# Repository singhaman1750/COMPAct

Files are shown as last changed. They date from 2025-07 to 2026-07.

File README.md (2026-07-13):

# COMPAct: Actuator design framework

This repository provides an implementation of the paper:

<td style="padding:20px;width:75%;vertical-align:middle">
      <a href="https://arxiv.org/abs/2510.07197" target="_blank">
      <b> COMPAct: Computational Optimization and Automated Modular design of Planetary Actuators </b>
      </a>
      <br>
      <a href="https://singhaman1750.github.io/" target="_blank">Aman Singh</a>, <a href="https://www.linkedin.com/in/deepak-kapa-iitr26/" target="_blank">Deepak Kapa</a>, <a href="https://www.linkedin.com/in/suryank-joshi/" target="_blank">Suryank Joshi</a>, and <a href="https://www.shishirny.com/" target="_blank">Shishir Kolathaya</a>
      <br>
      <em>IEEE International Conference on Robotics and Automation</em>, 2026
      <br>
      <a href="https://youtu.be/99zOKgxsDho?si=5hyMySFOMPunLLCl">Video-Overview</a>
    <br>
</td>

<br>

## COMPAct Flowchart

<p align="center">
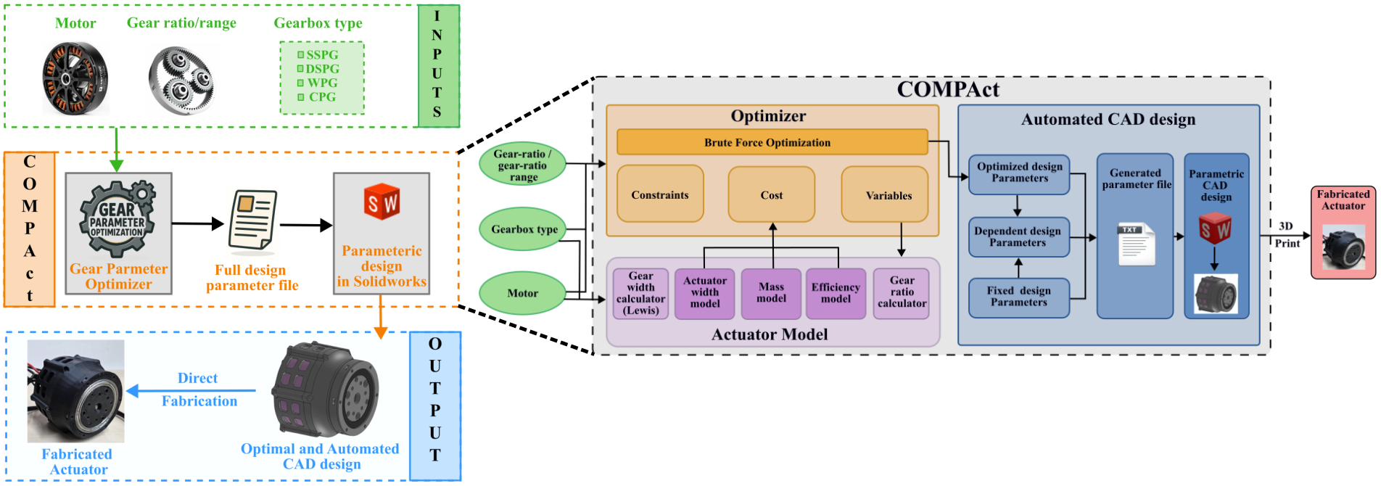
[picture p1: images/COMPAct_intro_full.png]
Flowchart of COMPAct: Actuator Design Framework
  
</p>

---

## Quick Start Guide

#### **Setup & Installations**
* **Step 1:** [Setup & Requirements](#step-1-setup--requirements)
* **Step 2:** [Installation](#step-2-installation)
* **Step 3:** [CAD Automation Setup](#step-3-cad-automation-setup-optional)

#### **Optimization & Automated design generation**
* **Step 4:** [Run Optimization](#step-4-run-optimization)
* **Step 5:** [View Results](#step-5-view-results)
* **Step 6:** [Generate Automated CAD designs](#step-6-generate-automated-cad-designs)
* **Step 7:** [3D-print and Assemble](#step-7-3d-print-and-assemble)

---

### Step 1: Setup & Requirements

#### System Requirements
* **Python 3.x**
* **SolidWorks 2024** (or higher) – *Required for CAD automation features.*

#### Recommended Terminal
* **Windows:** [Git Bash](https://git-scm.com/downloads) is highly recommended.
* **Linux/macOS:** Default terminal.

---

### Step 2: Installation
Clone the repository and install the dependencies:

```bash
# Clone the repository
git clone https://github.com/singhaman1750/COMPAct.git
```

```bash
# Enter the directory
cd COMPAct
```

```bash
# Install required packages
pip install numpy matplotlib pandas requests
```

---

### Step 3: CAD Automation Setup (Optional)

### Option A: *SolidWorks (Local)*

Due to file size limits, CAD files are zipped. You must extract them before running the framework.

**NOTE:** _If you only need the optimized gear parameters (teeth count, module, etc.), you can skip this step. Extraction is only required if you intend to use the **automated 3D modeling**._

1.  Navigate to the `CADs` directory.
2.  Inside each gearbox folder (e.g., `CADs/SSPG/`), unzip the archive (e.g., `sspg_actuator.zip`) into the **same directory**.

Your directory structure should look like this after extraction:
```text
COMPAct-Actuator_design_framework/
└── CADs/
    ├── SSPG/sspg_actuator/sspg_actuator/...
    ├── CPG/cpg_actuator/cpg_actuator/...
    ├── DSPG/dspg_actuator/dspg_actuator/...
    └── WPG/wpg_actuator/wpg_actuator/...
```

### Option B: *Onshape (Cloud-based)*

If you prefer not to use SolidWorks, the CAD models are also available on Onshape. No extraction or local files needed.

#### 1. SSPG (Single-Stage Planetary Gearbox)
[COPY PASTE THE LINK IF HYPERLINK DOESN'T OPEN] 

👉 **[Open SSPG in Onshape](https://cad.onshape.com/documents/c1aac326515ba734f63b9b3f/w/f9cccd7b90ce6d7934076c7c/e/11d494d64974a13f1ae2def2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)**

👉 **[Open CPG in Onshape](https://cad.onshape.com/documents/dabf50453c93c1c427cef77a/w/58e59ba240adf6d2a07794cc/e/2fd7bc338e9316193d1a2f79)**

👉 **[Open WPG in Onshape](https://cad.onshape.com/documents/ad699ddbc25bac5c32e33135/w/758de9a639163030bca8fa73/e/4cb254c85cc1f2d31a39a63a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)**

👉 **[Open DSPG in Onshape](https://cad.onshape.com/documents/b8d43d150fb932ea649dcd0f/w/aaa3fcc8da584cc207374389/e/12e148469fa8eb5b917f5bb1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)**

👉 **[Open ISSPG OutBearing in Onshape](https://cad.onshape.com/documents/bf5f13d9187efab731a95ba7/w/1261f6088846b1d6dd38ea32/e/9442fa2e352d23d6eb88bc6e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)**
```
https://cad.onshape.com/documents/bf5f13d9187efab731a95ba7/w/1261f6088846b1d6dd38ea32/e/9442fa2e352d23d6eb88bc6e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
```

👉 **[Open ISSPG InBearing in Onshape](https://cad.onshape.com/documents/9fa91e98fe82c4e544284d41/w/828f637e6a1fef0940224c5c/e/c80b77fbcf87c09b3b593c8a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)**
```
https://cad.onshape.com/documents/9fa91e98fe82c4e544284d41/w/828f637e6a1fef0940224c5c/e/c80b77fbcf87c09b3b593c8a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
```

👉 **[Open INCPG Dependent in Onshape](https://cad.onshape.com/documents/3e794c46f172f3b02cfa18e7/w/dfc878270d998ca1ea8223c8/e/c324bd70f7c31566e927c1f7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)**
```
https://cad.onshape.com/documents/3e794c46f172f3b02cfa18e7/w/dfc878270d998ca1ea8223c8/e/c324bd70f7c31566e927c1f7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
```

👉 **[Open INCPG Independent in Onshape](https://cad.onshape.com/documents/2519b08c3c51bbdac1923e25/w/095a9ef04c28fad58dcdbe6c/e/7335150ff09908ff2cd1b9b2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)**
```
https://cad.onshape.com/documents/2519b08c3c51bbdac1923e25/w/095a9ef04c28fad58dcdbe6c/e/7335150ff09908ff2cd1b9b2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
```

👉 **[Open INSSPG_Dependent in Onshape](https://cad.onshape.com/documents/97af418b118f30715235cd6a/w/253f8dd6e8e424cb9f7bb1dd/e/bcd4cd4dc6121c4e6915a50e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)**
```
https://cad.onshape.com/documents/97af418b118f30715235cd6a/w/253f8dd6e8e424cb9f7bb1dd/e/bcd4cd4dc6121c4e6915a50e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
```

👉 **[Open INSSPG_Independent in Onshape](https://cad.onshape.com/documents/e0cb8ed6bb2b36cfcadffcf4/w/a5de456488f59701ab182711/e/b8af8d5da69957495c24591f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)**
```
https://cad.onshape.com/documents/e0cb8ed6bb2b36cfcadffcf4/w/a5de456488f59701ab182711/e/b8af8d5da69957495c24591f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 
```

👉 **[Open ICPG in Onshape](https://cad.onshape.com/documents/1cec852caa1080765682d3d0/w/9b7913f319aab1fd6ef5de45/e/f9d06c56e5c97df7f6c68aa9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)** 
```
https://cad.onshape.com/documents/1cec852caa1080765682d3d0/w/9b7913f319aab1fd6ef5de45/e/f9d06c56e5c97df7f6c68aa9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 
```

To get your own editable copy:
1. Open the link above — you will see the model in view-only mode
2. Click the **Onshape logo / menu icon** in the top-left corner
3. Select **"Make a copy"**
4. Give it a name and save it to your own Onshape workspace

> ✅ Your copy is fully independent — any changes you make will **not** affect the original shared document. You can now edit the Variable Studio, modify geometry, and run the automation script against your own copy.

---

### Step 4: Run Optimization
Run the Python script from the root directory to generate optimal gear parameters.

**Syntax:**
```bash
python actOpt.py <motor> <gearbox> <ratio>
```
* **`<motor>`**: U8, U10, U12, MN8014, VT8020, MAD_M6C12 , RO100 , RI100 , RO80
* **`<gearbox>`**: sspg, cpg, dspg, wpg , icpg , insspg_type_1 {Independent} , insspg_type_2 {Dependent} 
* **`<ratio>`**: Must be a value > 2.

**Example:**
To optimize a **RO100** with a **Internal-Compound-Planetary Gearbox** and a **ratio of 6.5**:

```bash
python actOpt_icpg.py RO100 icpg 6.5
```

---
**Example:**
To optimize a **RI100** with a **Inrunner-Dependent-Single-Stage Planetary Gearbox** and a **ratio of 6.5**:

```bash
python actOpt_insspg.py RI100 insspg_type_2 6.5
```

---
**Example:**
To optimize a **RI100** with a **Inrunner-Independent-Single-Stage Planetary Gearbox** and a **ratio of 6.5**:

```bash
python actOpt_insspg.py RI100 insspg_type_1 6.5
```

**Syntax for ISSPG:**  
```bash
python <actuator_type>.py <motor> isspg <ratio>
```
* **`<actuator_type>`**: ISSPG_inside_gen_eq, ISSPG_compact_gen_eq
* **`<motor>`**: RO80, RO100
* **`<ratio>`**: Must be a value > 2.  
Note: ISSPG_inside_gen_eq is for InBearing design and ISSPG_compact_gen_eq is for OutBearing design
  
**Example:**
To optimize **RO100** with an **Internal Single-Stage Planetary Gearbox InBearing** and a **ratio of 6.5**:

```bash
python ISSPG_inside_gen_eq.py RO100 isspg 6.5
```

**Syntax for INCPG:**
```bash
python <actuator_type>.py <motor> incpg <ratio>
```
* **`<actuator_type>`**: InrunnerCPG_independent_gen_eq, InrunnerCPG_dependent_gen_eq
* **`<motor>`**: RI100
* **`<ratio>`**: Must be a value > 2.
  
**Example:**
To optimize **RI100** with an **Inrunner Compound Planetary Gearbox Independent** and a **ratio of 6.5**:

```bash
python InrunnerCPG_independent_gen_eq.py RI100 incpg 6.5
```

---

### Step 5: View Results
The script will output the optimal geometric parameters directly in the terminal:

```text
Running optimization:
  Motor       : U8
  Gearbox     : sspg
  Gear Ratio  : 6.5
Time taken: 0.0196 sec
Optimization Completed.
-------------------------------
Optimal Parameters:
Number of teeth: Sun(Ns): 23 , Planet(Np): 52 , Ring(Nr): 127 , Module(m): 0.6 , NumPlanet(n_p): 3
---
Gear Ratio(GR): 6.52 : 1
-------------------------------
```

Detailed parameter files are automatically generated in the following locations:

* **SSPG:** `CADs/SSPG/sspg_equations.txt`
* **CPG:** `CADs/CPG/cpg_equations.txt`
* **DSPG:** `CADs/DSPG/dspg_equations.txt`
* **WPG:** `CADs/WPG/wpg_equations.txt`
  
#### MASS ANALYSIS
```
https://docs.google.com/spreadsheets/d/1QYUox6946nNlciWFAQ1L-EqQNLNdAT6GV0OtC5uI0eU/edit?usp=sharing
```
---

### Step 6: Generate Automated CAD designs

There are two ways to apply the optimization results to a CAD model — using **SolidWorks** (local) or **Onshape** (cloud-based). Both use the same equations file generated in Step 2.

#### Option A: SolidWorks (Local)

**NOTE:** _If you skipped the CAD extraction in Step 2, you cannot use this option._

1.  Open **SolidWorks**.
2.  Open the assembly file (`.SLDASM`) for your specific gearbox type:
    * **SSPG:** `CADs/SSPG/sspg_actuator/sspg_actuator/sspg_actuator.SLDASM`
    * *(Paths for CPG, DSPG, and WPG follow the same folder pattern)*
3.  Click the **Rebuild** (Traffic Light) icon.
4.  The 3D model will automatically update to reflect the calculated parameters.

---

#### Option B: Onshape (Cloud-based)

This extension lets you push optimization results directly to a parametric Onshape CAD model via the Onshape REST API — no SolidWorks or local CAD files required.

##### i. Make a Copy of the Onshape Document

If you haven't already done so in the extraction step above, open the shared Onshape document and make your own copy:

👉 **[Open SSPG in Onshape](https://cad.onshape.com/documents/c1aac326515ba734f63b9b3f/w/f9cccd7b90ce6d7934076c7c/e/11d494d64974a13f1ae2def2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)**

👉 **[Open CPG in Onshape](https://cad.onshape.com/documents/dabf50453c93c1c427cef77a/w/58e59ba240adf6d2a07794cc/e/2fd7bc338e9316193d1a2f79)**

👉 **[Open WPG in Onshape](https://cad.onshape.com/documents/ad699ddbc25bac5c32e33135/w/758de9a639163030bca8fa73/e/4cb254c85cc1f2d31a39a63a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)**

👉 **[Open DSPG in Onshape](https://cad.onshape.com/documents/b8d43d150fb932ea649dcd0f/w/aaa3fcc8da584cc207374389/e/12e148469fa8eb5b917f5bb1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)**

1. Click the **Onshape logo / menu icon** in the top-left corner
2. Select **"Make a copy"**
3. Give it a name and save it to your own Onshape workspace

> ✅ Your copy is fully independent — any changes the script makes will **not** affect the original shared document.

##### ii. Generate Onshape API Keys

The script authenticates with the Onshape REST API using personal API keys.

1. Go to [dev-portal.onshape.com](https://dev-portal.onshape.com) and sign in
2. Navigate to **API Keys** → **Create New API Key**
3. Copy the **Access Key** and **Secret Key**
4. Create a file named `.env` inside the `Onshape_extension/` folder with the following content:

```env
ONSHAPE_ACCESS_KEY=your_access_key
ONSHAPE_SECRET_KEY=your_secret_key
```

> 🔒 **Never commit your `.env` file.** Make sure `.env` is listed in your `.gitignore`.

##### iii. Get Your Variable Studio URL

The script needs to know which Onshape document and Variable Studio to update. This is done via the URL in your browser.

1. Open your **copied** Onshape document
2. Click on the **Variable Studio** tab at the bottom of the screen (it appears alongside part studios and assemblies)
3. Once you are on the Variable Studio page, copy the **full URL** from your browser's address bar — it will look something like:
   ```
   https://cad.onshape.com/documents/abc123.../w/def456.../e/ghi789...
   ```
4. Open `Onshape_extension/set_values.py` and paste the URL into the `url` field:
   ```python
   doc = Document.from_url(
       url="https://cad.onshape.com/documents/<your-url-here>"
   )
   ```

> 💡 This URL encodes your document ID, workspace ID, and element ID — it is unique to your copy. Using the original shared link will fail as you do not have write access to it.

<!-- ##### iv. Set the Equations File

In `set_values.py`, make sure the equations file name matches the one generated by the optimizer in Step 2. For SSPG this will be:

```python
variables_to_set = parse_variable_file("sspg_equations.txt")
```

Update the filename if you are running a different gearbox type (e.g., `cpg_equations.txt`). -->

##### iv. Run the Script

From the root of the repository:

```bash
cd Onshape_extension
python3 set_values.py
```

The script will print the variable values before and after the update so you can confirm the changes were applied correctly:

```text
=== BEFORE ===
{ ... current variable values ... }

=== SETTING VARIABLE ===
[POST] /api/variables/d/.../w/.../e/.../variables  →  200

=== AFTER ===
{ ... updated variable values ... }
```

> ⚠️ A `200` status does not always mean the update succeeded — Onshape returns 200 even for malformed payloads. Always check the `AFTER` output to confirm your variables were updated as expected.

---

### Step 7: 3D-print and Assemble
* **3D Printing:** Export the updated plastic parts to `.STL` format.
* **Bearings:** Check the updated CAD model to identify which standard bearings are required for your specific configuration.

----

This framework provides the following features:
1. **Optimize planetary gearbox** parameters for a **given motor** across the following gearbox types:
      - Single Stage Planetary Gearbox (SSPG),
      - Compound Planetary Gearbox (CPG),
      - Wolfrom Planetary Gearbox (3K)(WPG), and
      - Double Stage Planetary Gearbox (DSPG).

2. Perform multi-objective optimization to **minimize actuator mass** and **axial width** while **maximizing efficiency**.
3. **Automatically generate parametric actuator CAD** from optimization results, enabling direct **3D printing without manual redesign**.

----

## ✅ Supported Hardware

### Supported Motors
| Motor Code | Description |
| :--- | :--- |
| **U8** | T-motor U8 |
| **U10** | T-motor U10+ |
| **U12** | T-motor U12 |
| **MN8014** | T-motor MN8014 |
| **VT8020** | Vector Techniques 8020 |
| **MAD_M6C12**| MAD Components M6C12 |

### Supported Gearbox Topologies
| Type | Description |
| :--- | :--- |
| **sspg** | Single-Stage Planetary Gearbox |
| **cpg** | Compound Planetary Gearbox |
| **wpg** | Wolfrom Planetary Gearbox (3K) |
| **dspg** | Double-Stage Planetary Gearbox |

---

## 📄 Citation

If you use this framework in your research, please cite:

```bibtex
@misc{singh2025compact,
      title={COMPAct: Computational Optimization and Automated Modular design of Planetary Actuators}, 
      author={Aman Singh and Deepak Kapa and Suryank Joshi and Shishir Kolathaya},
      year={2025},
      eprint={2510.07197},
      archivePrefix={arXiv},
      primaryClass={cs.RO},
      url={https://arxiv.org/abs/2510.07197}, 
}
```

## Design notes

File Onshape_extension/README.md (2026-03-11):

## Quick Start (Run the Project)

### 1. Go to the project root
```bash
cd onshape_toolkit
```
### 2. Activate the virtual environment
```bash
source venv/bin/activate
```
### 4. pip install
```bash
pip install onshape-robotics-toolkit
pip install numpy matplotlib pandas
```

### NOTE 
```bash
AFTER INSTALLING THE "onshape-robotics-toolkit"
Go to connect.py in the library and add the print response statement in the "set_variables" method to see the error
```

### 5. Run the script
```bash
set_values.py
```

# Onshape CAD Automation Toolkit

A Python-based toolkit for programmatic control of Onshape CAD models — enabling parametric variable updates, design automation, and CAD-driven engineering pipelines via the Onshape REST API.

---

## Why This Exists

Most CAD workflows are still manual. Even in parametric design, engineers are left clicking through menus to update dimensions, run sweeps, or test variants.

This toolkit breaks that bottleneck. It lets you treat your CAD model as a programmable object — read variables, push updates, run iterations — all from Python.

Built while working on actuator and mechanism design, where manually updating link lengths across dozens of configurations wasn't sustainable.

---

## Features

- Authenticate with the Onshape API (v9)
- Traverse documents and retrieve elements
- Access and parse Variable Studios
- Read variable names, types, and expressions
- Update variables programmatically with API-compliant payloads
- Handle type-aware updates (`LENGTH`, `ANGLE`, `NUMBER`)
- Structured logging for debugging API responses

---

## Repository Structure

```
onshape-toolkit/
│
├── connect.py              # API client initialization and auth
├── variables.py            # Core variable read/write logic
├── set_values.py           # Script: update specific variables
├── update_variables.py     # Script: batch parametric updates
├── utils/                  # Shared helpers and formatting
├── .env                    # API credentials (not committed)
└── README.md
```

---

## Setup

### 1. Clone

```bash
git clone https://github.com/sakethvegesna/onshape-toolkit.git
cd onshape-toolkit
```

### 2. Install Dependencies

```bash
pip install requests python-dotenv
```

### 3. Configure Credentials

Create a `.env` file in the project root:

```env
ONSHAPE_ACCESS_KEY=your_access_key
ONSHAPE_SECRET_KEY=your_secret_key
ONSHAPE_BASE_URL=https://cad.onshape.com
```

API keys can be generated at [dev-portal.onshape.com](https://dev-portal.onshape.com).

---

## Usage

### Reading Variables

```python
from variables import get_variables

variables = get_variables(document_id, workspace_id, element_id)
print(variables)
```

### Updating Variables

```python
from variables import set_variables

set_variables(
    document_id,
    workspace_id,
    element_id,
    {
        "link_length": "250 mm",
        "joint_width": "40 mm",
        "clearance_angle": "15 deg"
    }
)
```

---

## API Notes

The Onshape Variables API requires strictly formatted payloads. Key implementation details:

- Variables must be sent as **expressions**, not raw numbers (e.g., `"250 mm"` not `250`)
- Each variable requires an explicit **type** field (`LENGTH`, `ANGLE`, `NUMBER`)
- Malformed payloads return 200 OK but silently fail — this toolkit validates before sending
- Developed and tested against Onshape API v9

---

## Use Cases

- Parametric dimension sweeps for mechanism design
- Actuator geometry iteration (link lengths, joint offsets)
- CAD integration into optimization or ML pipelines
- Batch geometry generation for simulation datasets
- Robotics leg/arm configuration studies

---

## Roadmap

- [ ] Assembly-level parameter control
- [ ] Feature creation and suppression
- [ ] STEP/STL export automation
- [ ] Optimization loop integration (e.g., SciPy, Optuna)
- [ ] CLI interface for quick variable updates

---

## Security

Never commit your `.env` file. Add it to `.gitignore`:

```
.env
```

---

## Author

**Saketh Vegesna**  
Mechanical Engineering — Robotics  
Focused on automation, mechanism design, and computational engineering.

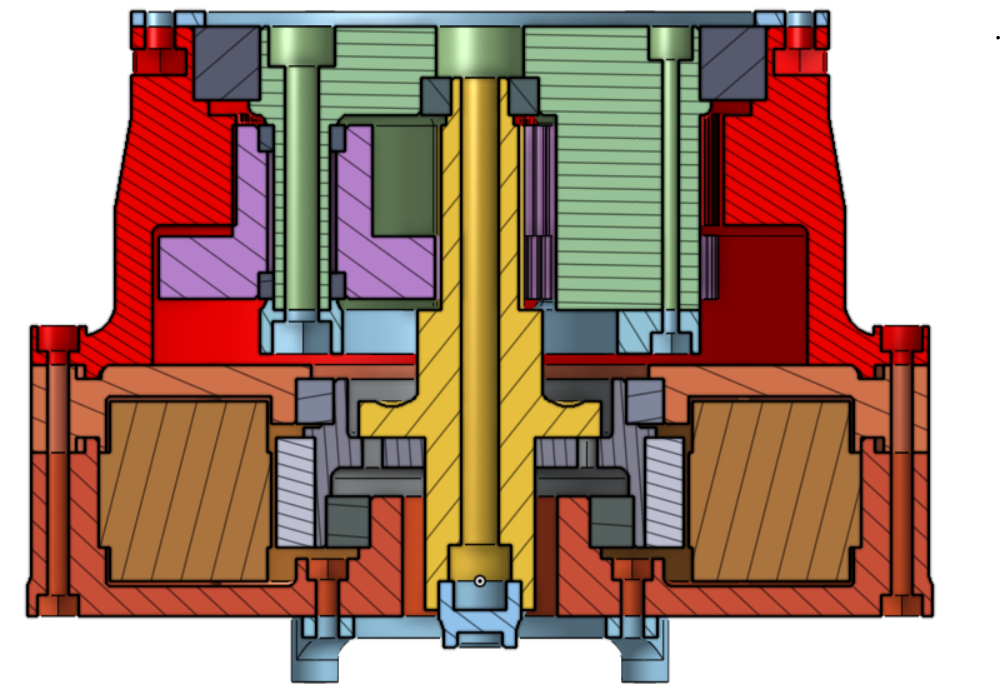
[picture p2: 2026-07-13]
Images/Actuator Cross-Section/INCPG_independent.png

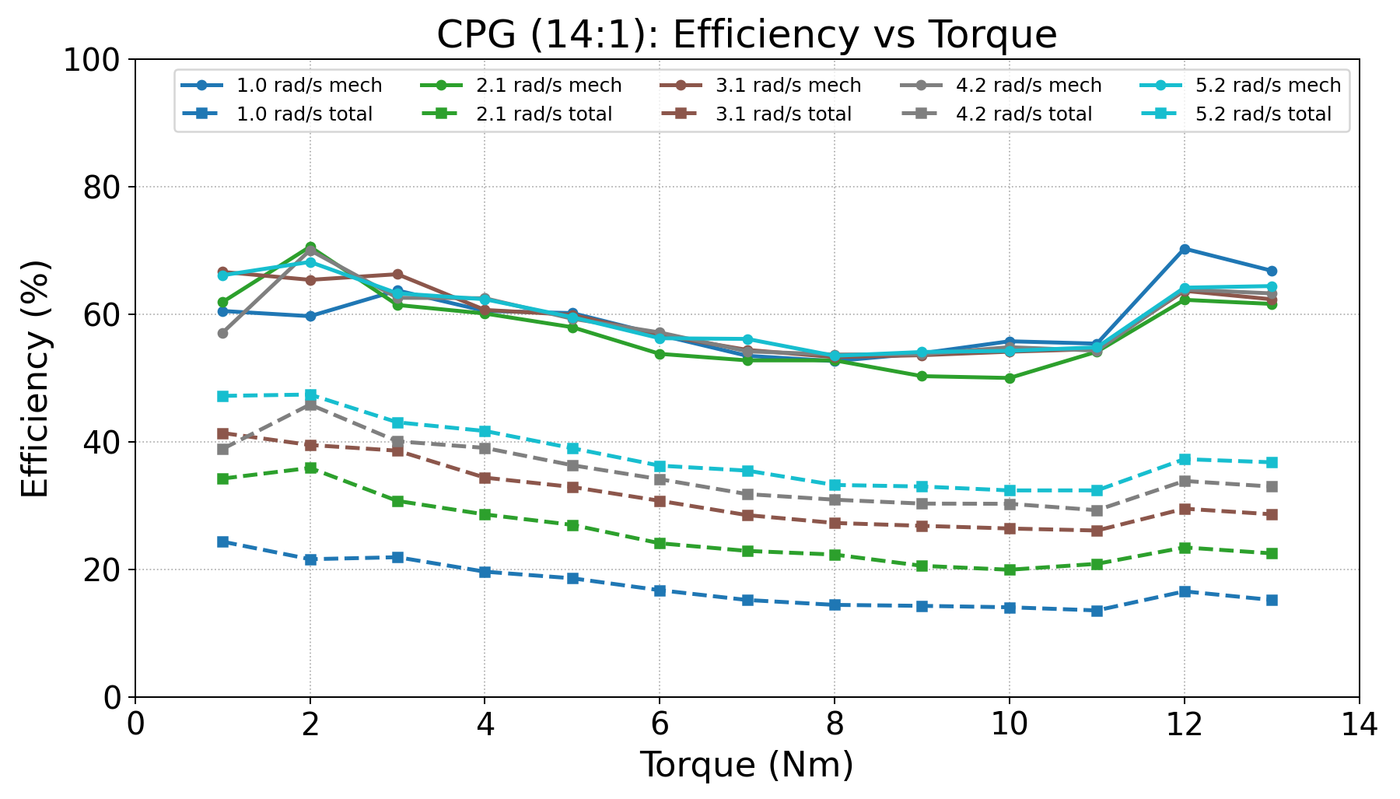
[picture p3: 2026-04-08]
images/CPG_power_eff.png

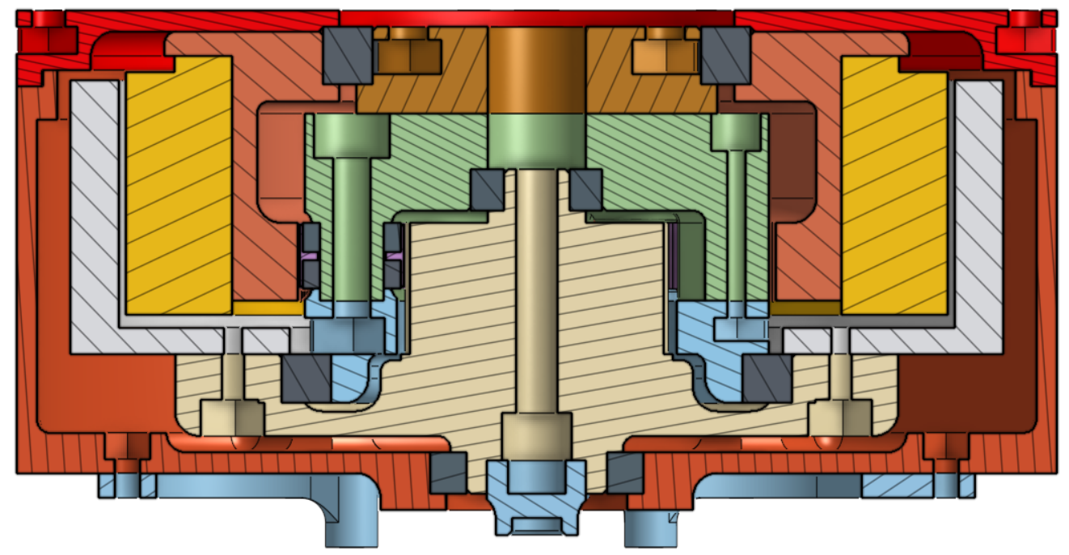
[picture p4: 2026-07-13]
Images/Actuator Cross-Section/ISSPG outside bearing.png

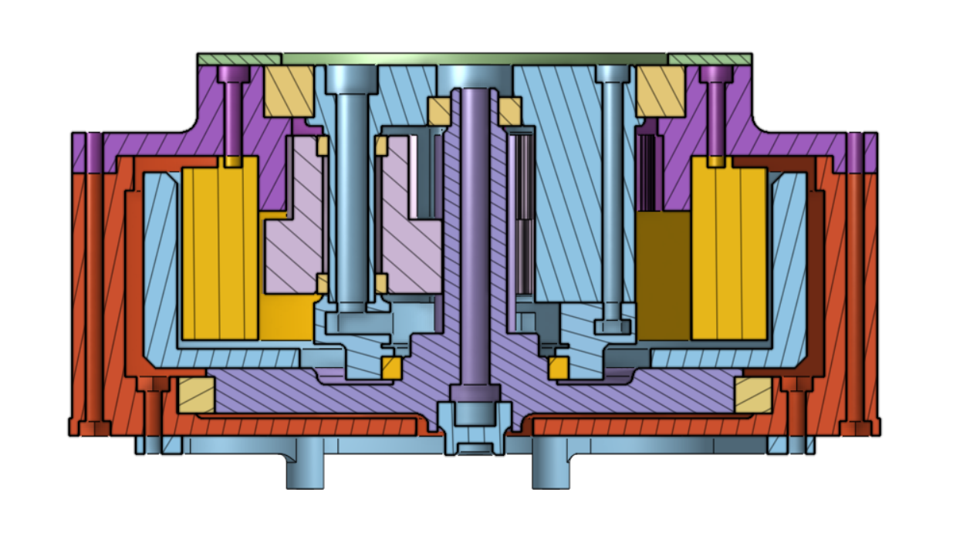
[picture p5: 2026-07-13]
Images/Actuator Cross-Section/ICPG.png

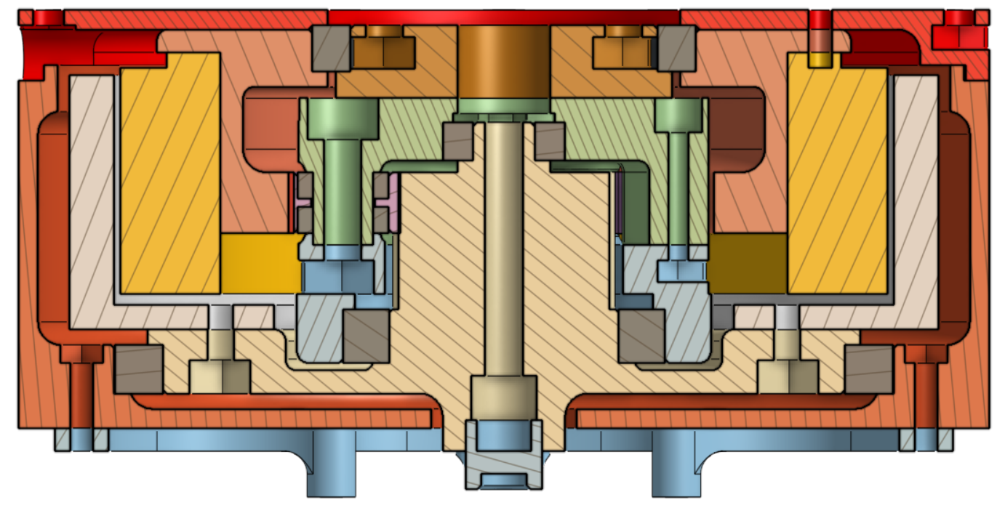
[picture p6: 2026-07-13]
Images/Actuator Cross-Section/ISSPG inside bearing.png

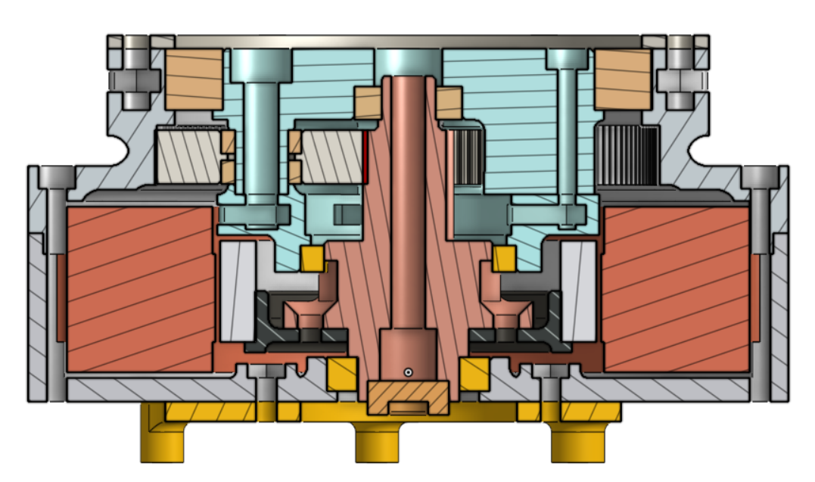
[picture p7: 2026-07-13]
Images/Actuator Cross-Section/INSSPG_Dependent.png

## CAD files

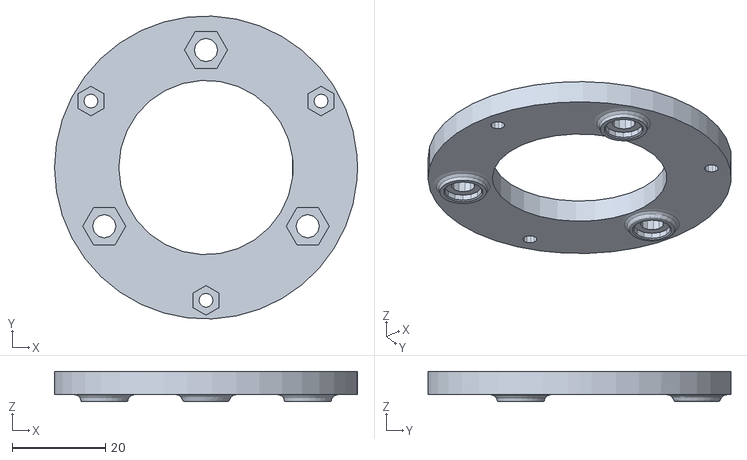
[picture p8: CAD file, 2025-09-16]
CADs/Actuator_STL_files/cpg_14/cpg_sec_carrier.STL
65.0 x 64.9 x 6.50

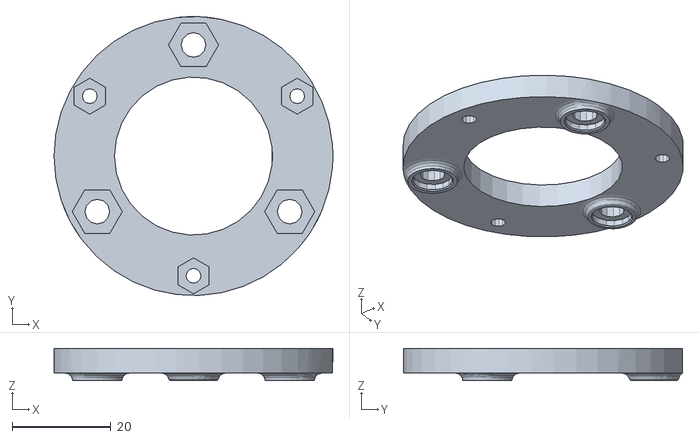
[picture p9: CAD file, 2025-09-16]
CADs/Actuator_STL_files/sspg_7.2/sspg_sec_carrier.STL
56.5 x 56.5 x 6.50

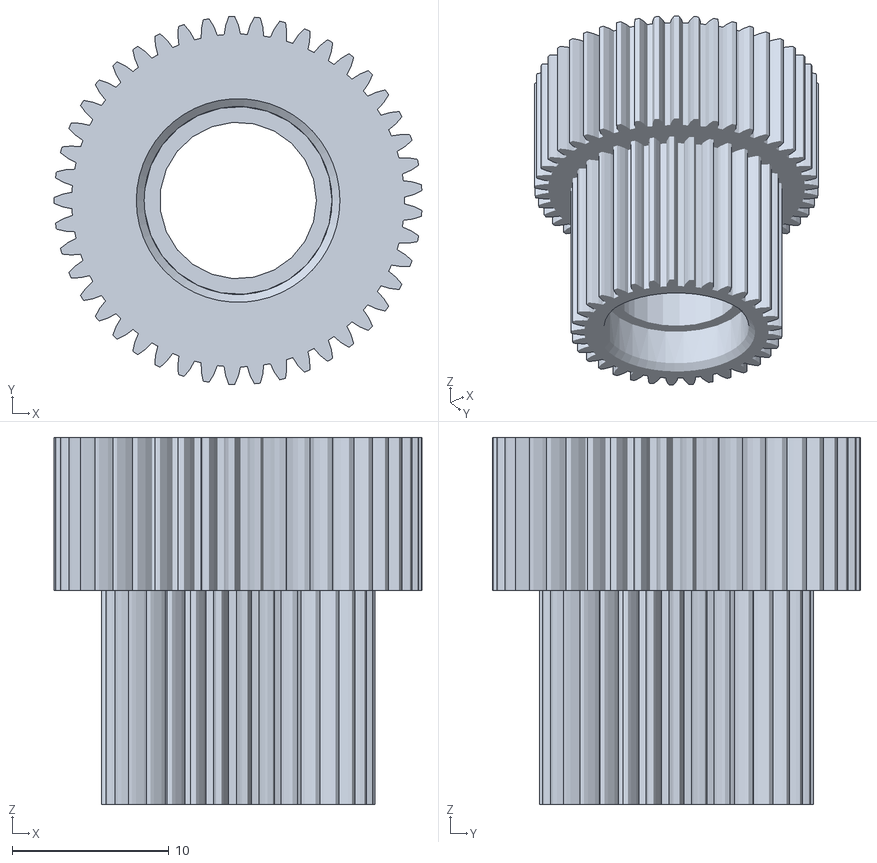
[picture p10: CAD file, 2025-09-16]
CADs/Actuator_STL_files/wpg_16/wpg_planet.STL
23.5 x 23.5 x 23.4

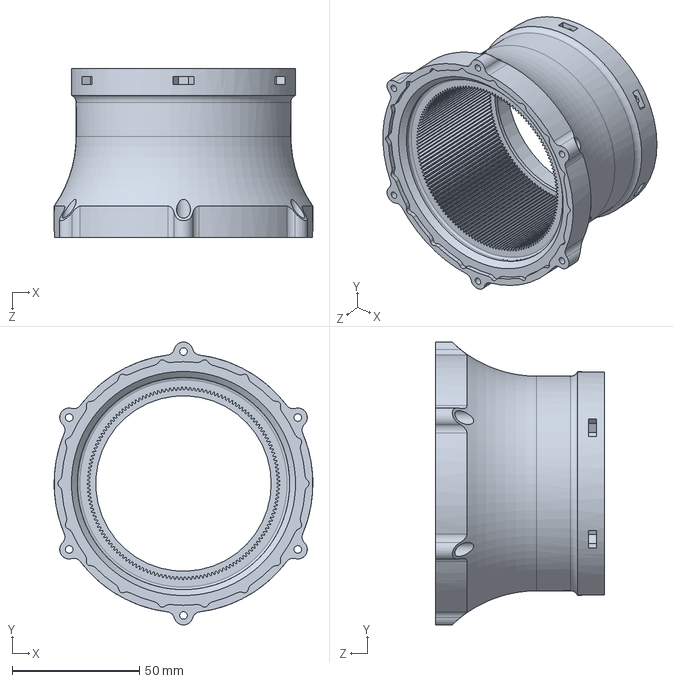
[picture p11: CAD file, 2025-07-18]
SSPG/sspg_gearbox_casing.SLDPRT
101.8 x 111.3 x 66.3 mm

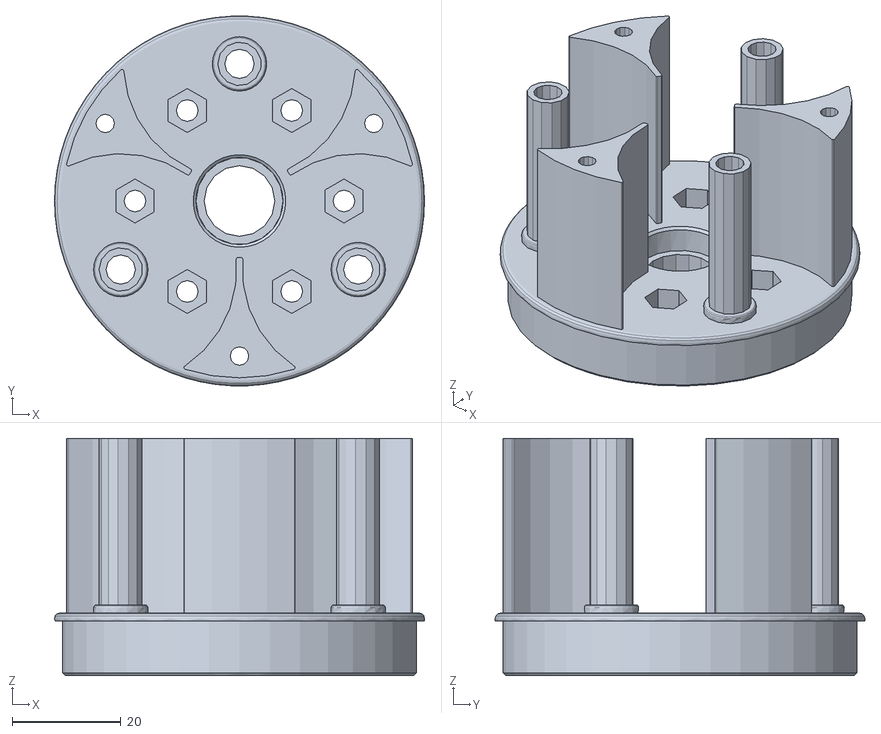
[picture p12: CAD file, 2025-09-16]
CADs/Actuator_STL_files/cpg_14/cpg_carrier.STL
68.0 x 67.9 x 43.6

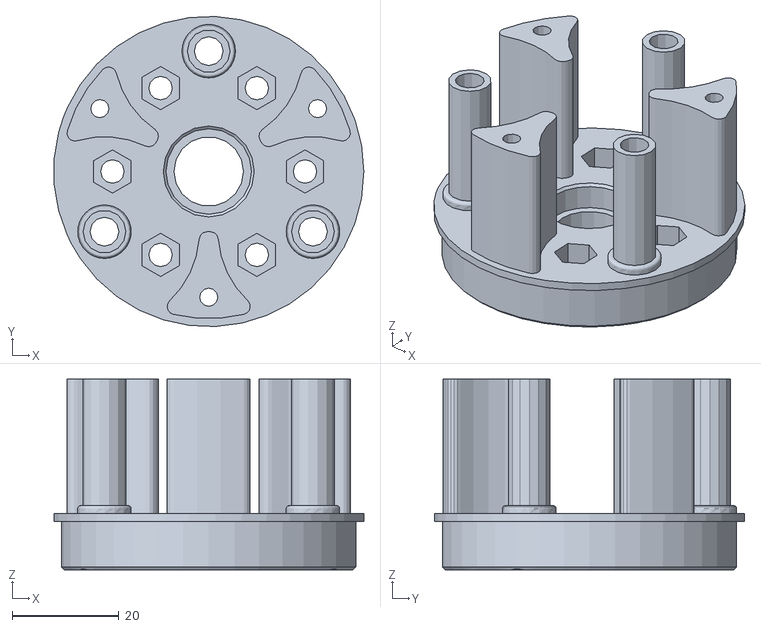
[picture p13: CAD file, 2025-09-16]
CADs/Actuator_STL_files/sspg_7.2/sspg_carrier_updated.STL
57.9 x 57.9 x 35.6

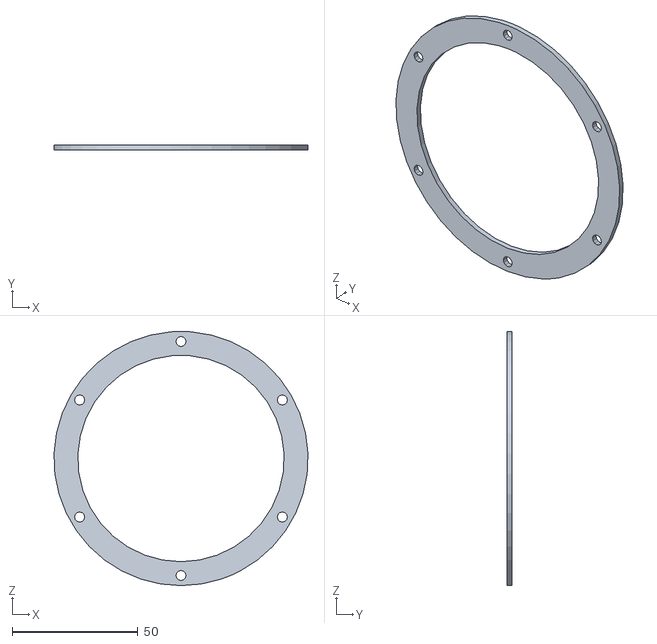
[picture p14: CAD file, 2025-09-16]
CADs/Actuator_STL_files/wpg_16/wpg_bearing_retainer.STL
100.9 x 2.00 x 101.0

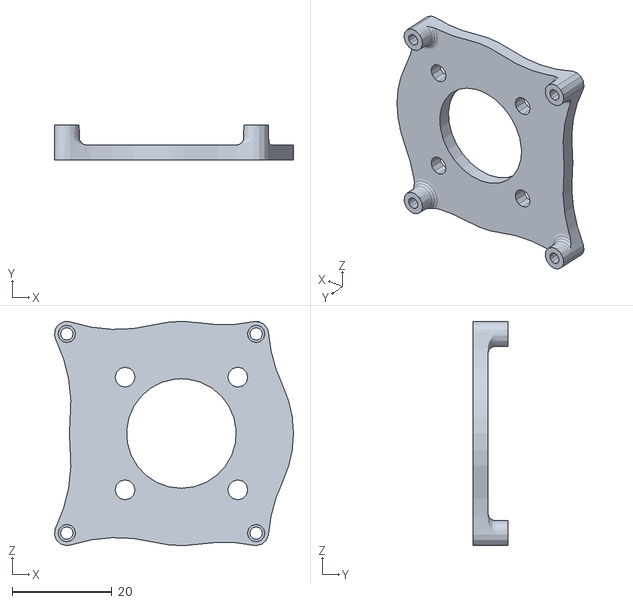
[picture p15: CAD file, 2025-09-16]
CADs/Actuator_STL_files/cpg_14/cpg_driver_mount.STL
48.0 x 7.00 x 45.0

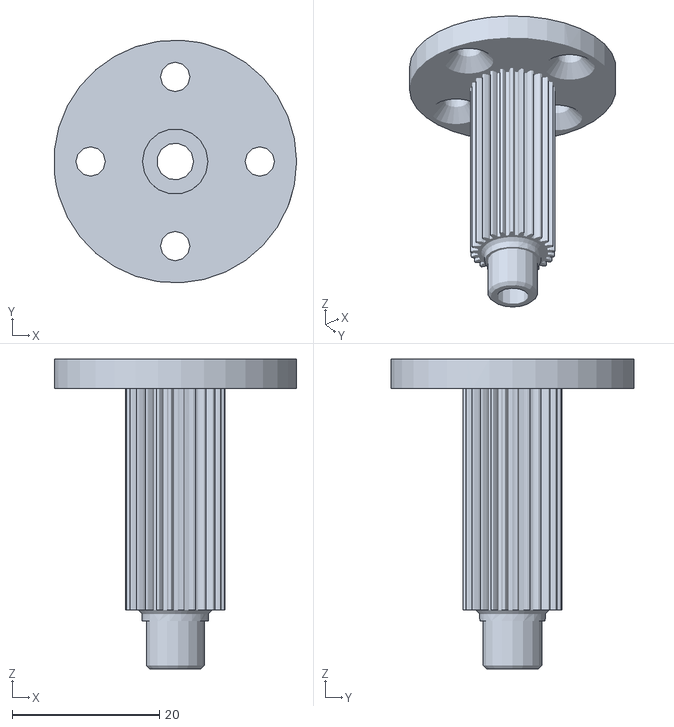
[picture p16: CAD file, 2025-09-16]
CADs/Actuator_STL_files/sspg_7.2/sspg_sun.STL
32.9 x 33.0 x 42.1

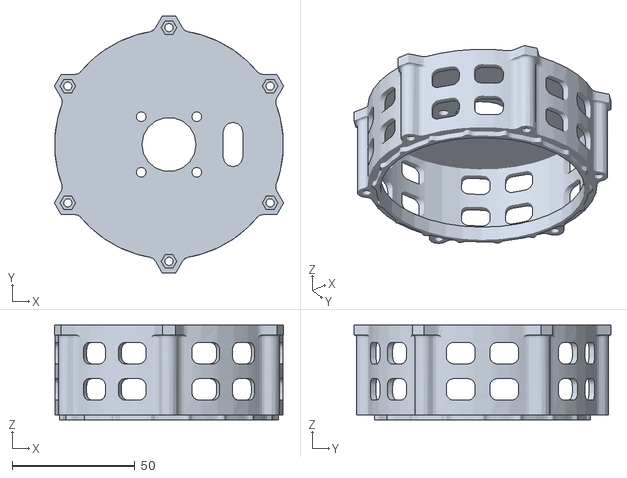
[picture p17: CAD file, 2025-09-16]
CADs/Actuator_STL_files/wpg_16/wpg_motor_casing.STL
93.2 x 104.5 x 38.5

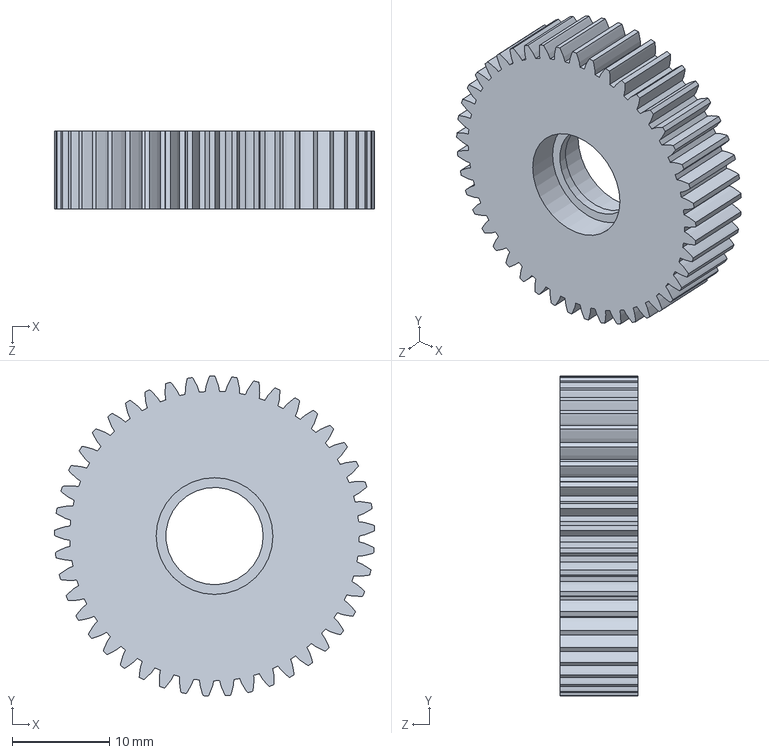
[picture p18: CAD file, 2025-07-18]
SSPG/sspg_planet.SLDPRT
32.9 x 32.9 x 8.00 mm

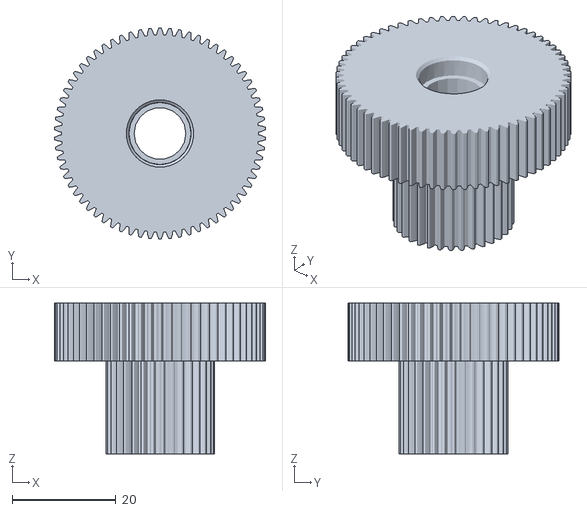
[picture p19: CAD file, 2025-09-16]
CADs/Actuator_STL_files/cpg_14/cpg_planet.STL
40.8 x 40.8 x 29.1

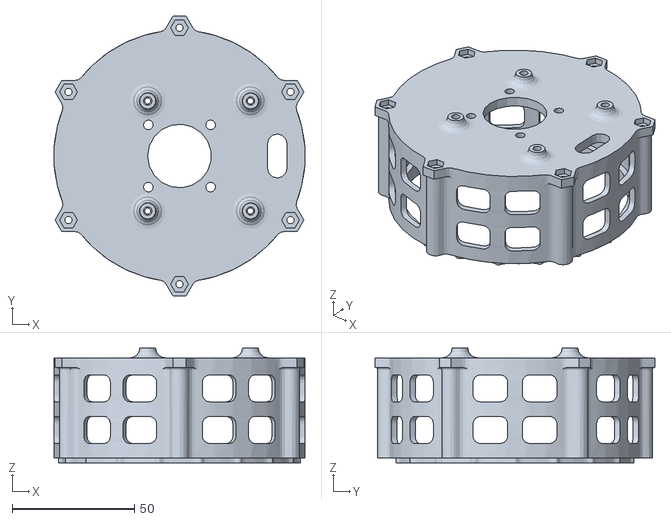
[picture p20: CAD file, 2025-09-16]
CADs/Actuator_STL_files/sspg_7.2/sspg_motor_casing.STL
102.6 x 114.3 x 47.0

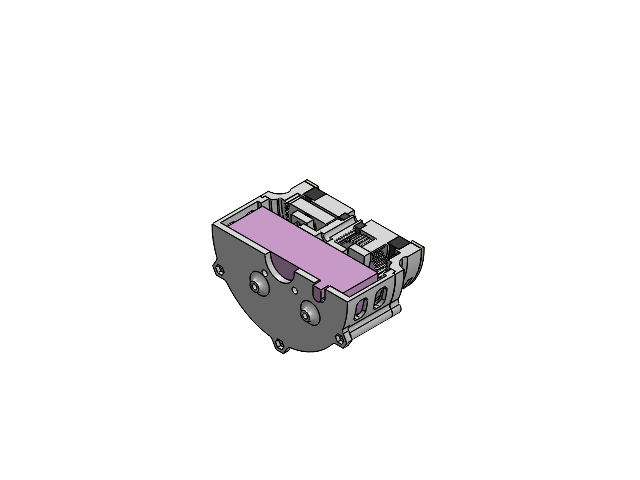
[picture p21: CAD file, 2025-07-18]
SSPG/sspg_actuator.SLDASM
sspg_gearbox_casing
sspg_motor_casing
sspg_sec_carrier
sspg_bearing
sspg_carrier
sspg_planet x 3
sspg_motor
sspg_sun
sspg_planet_bearing x 6
sspg_sun_shaft_bearing
sspg_bearing_retainer

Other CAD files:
CADs/Actuator_STL_files/cpg_14/cpg_bearing_retainer.STL
CADs/Actuator_STL_files/cpg_14/cpg_gearbox_casing.STL
CADs/Actuator_STL_files/cpg_14/cpg_motor_casing.STL
CADs/Actuator_STL_files/cpg_14/cpg_sun.STL
CADs/Actuator_STL_files/sspg_7.2/sspg_bearing_retainer.STL
CADs/Actuator_STL_files/sspg_7.2/sspg_carrier.STL
CADs/Actuator_STL_files/sspg_7.2/sspg_gearbox_casing.STL
CADs/Actuator_STL_files/sspg_7.2/sspg_planet.STL
CADs/Actuator_STL_files/wpg_16/wpg_carrier.STL
CADs/Actuator_STL_files/wpg_16/wpg_driver_mount.STL
CADs/Actuator_STL_files/wpg_16/wpg_gearbox_casing.STL
CADs/Actuator_STL_files/wpg_16/wpg_sec_carrier.STL
CADs/Actuator_STL_files/wpg_16/wpg_small_ring.STL
CADs/Actuator_STL_files/wpg_16/wpg_small_ring_bearing_shaft.STL
CADs/Actuator_STL_files/wpg_16/wpg_sun.STL
CADs/CPG/cpg_actuator/cpg_bearing.SLDPRT
CADs/CPG/cpg_actuator/cpg_bearing_retainer.SLDPRT
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

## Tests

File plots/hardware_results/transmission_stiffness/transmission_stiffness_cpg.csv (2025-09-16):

time_s | encoder_pos_rad | output_torque_Nm
0.010679 | -0.226267082 | 0.025000
0.021350 | -0.225558748 | 0.050000
0.032165 | -0.225842718 | 0.075000
0.042807 | -0.225152455 | 0.100000
0.053697 | -0.224283692 | 0.125000
0.064550 | -0.222317811 | 0.150000
0.075056 | -0.221546561 | 0.175000
0.085633 | -0.219974521 | 0.200000
0.096608 | -0.217884491 | 0.225000
0.107147 | -0.213606263 | 0.250000
0.117720 | -0.204398820 | 0.275000
0.128325 | -0.190740128 | 0.300000
0.138996 | -0.176094750 | 0.325000
0.149552 | -0.166438226 | 0.350000
0.160349 | -0.151883994 | 0.375000
0.170984 | -0.149754500 | 0.400000
0.181688 | -0.151026653 | 0.425000
0.192361 | -0.149551470 | 0.450000
0.203075 | -0.149593087 | 0.475000
0.213770 | -0.149621971 | 0.500000
0.224889 | -0.147608247 | 0.525000
0.235687 | -0.146323875 | 0.550000
0.246268 | -0.144261793 | 0.575000
0.256854 | -0.139245880 | 0.600000
0.267547 | -0.128032577 | 0.625000
0.278244 | -0.110889424 | 0.650000
0.288891 | -0.088638979 | 0.675000
0.299573 | -0.062141249 | 0.700000
0.310316 | -0.028581487 | 0.725000
0.321035 | 0.007464393 | 0.750000
0.331779 | 0.035611312 | 0.775000
0.342472 | 0.041571216 | 0.800000
0.353266 | 0.033364363 | 0.825000
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

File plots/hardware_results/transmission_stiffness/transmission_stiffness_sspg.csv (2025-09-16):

time_s | encoder_pos_rad | output_torque_Nm
0.010764 | -0.262032831 | 0.025000
0.021525 | -0.261688659 | 0.050000
0.032201 | -0.262291240 | 0.075000
0.042922 | -0.261923474 | 0.100000
0.053585 | -0.261790150 | 0.125000
0.064603 | -0.261637726 | 0.150000
0.075477 | -0.261046379 | 0.175000
0.086033 | -0.261244119 | 0.200000
0.096486 | -0.260882719 | 0.225000
0.107111 | -0.260419080 | 0.250000
0.117666 | -0.258979849 | 0.275000
0.128315 | -0.255326159 | 0.300000
0.139002 | -0.230862611 | 0.325000
0.149629 | -0.193940712 | 0.350000
0.160333 | -0.191120674 | 0.375000
0.171046 | -0.190283651 | 0.400000
0.181693 | -0.192024734 | 0.425000
0.192446 | -0.191766698 | 0.450000
0.203217 | -0.190867132 | 0.475000
0.213845 | -0.191086594 | 0.500000
0.225090 | -0.190964504 | 0.525000
0.235822 | -0.190691489 | 0.550000
0.246406 | -0.190659281 | 0.575000
0.256992 | -0.190761147 | 0.600000
0.267596 | -0.190922934 | 0.625000
0.278191 | -0.190753657 | 0.650000
0.288782 | -0.190536068 | 0.675000
0.299460 | -0.190245825 | 0.700000
0.310109 | -0.190111377 | 0.725000
0.320738 | -0.189790799 | 0.750000
0.331439 | -0.189845103 | 0.775000
0.342095 | -0.189897159 | 0.800000
0.352838 | -0.189421161 | 0.825000
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

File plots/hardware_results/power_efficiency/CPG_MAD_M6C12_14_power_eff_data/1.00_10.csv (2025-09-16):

time_s | load_velocity | load_torque | test_velocity | test_torque | loadcell_torque_nm | load_voltage | load_current | test_voltage | test_current
0.01 | -0.00 | -0.13 | -0.11 | 0.00 | -0.02 | 47.82 | 0.00 | 47.89 | -0.00
0.02 | 0.07 | -0.23 | 0.10 | 0.00 | -0.02 | 47.81 | 0.00 | 47.90 | -0.00
0.03 | 0.01 | -0.15 | 0.10 | 0.00 | -0.02 | 47.82 | 0.00 | 47.90 | -0.00
0.03 | 0.10 | -0.27 | 0.16 | 0.00 | -0.02 | 47.82 | 0.00 | 47.89 | -0.00
0.04 | 0.11 | -0.28 | -0.06 | 0.00 | -0.03 | 47.82 | 0.00 | 47.89 | -0.00
0.05 | -0.02 | -0.11 | -0.08 | 0.00 | -0.03 | 47.82 | 0.00 | 47.89 | -0.00
0.07 | 0.13 | -0.31 | -0.04 | 0.00 | -0.03 | 47.82 | 0.00 | 47.89 | 0.00
0.07 | 0.04 | -0.19 | -0.08 | 0.00 | -0.03 | 47.82 | 0.00 | 47.89 | -0.00
0.09 | 0.14 | -0.33 | 0.05 | 0.00 | -0.03 | 47.82 | 0.00 | 47.89 | 0.00
0.10 | 0.04 | -0.20 | 0.10 | 0.00 | -0.03 | 47.83 | 0.00 | 47.90 | 0.00
0.10 | -0.02 | -0.25 | 0.02 | 0.02 | -0.03 | 47.82 | 0.00 | 47.90 | 0.00
0.11 | 0.07 | -0.37 | 0.11 | 0.02 | -0.03 | 47.82 | 0.00 | 47.90 | -0.00
0.12 | -0.00 | -0.28 | -0.08 | 0.02 | -0.03 | 47.82 | 0.00 | 47.90 | 0.00
0.14 | -0.00 | -0.29 | 0.10 | 0.02 | -0.03 | 47.81 | 0.00 | 47.89 | 0.00
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

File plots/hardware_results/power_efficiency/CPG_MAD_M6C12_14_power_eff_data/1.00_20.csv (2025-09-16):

time_s | load_velocity | load_torque | test_velocity | test_torque | loadcell_torque_nm | load_voltage | load_current | test_voltage | test_current
0.01 | 0.01 | -0.27 | -0.12 | 0.00 | -0.00 | 47.82 | 0.00 | 47.89 | -0.00
0.02 | -0.00 | -0.27 | -0.10 | 0.00 | -0.00 | 47.82 | 0.00 | 47.89 | -0.00
0.02 | 0.05 | -0.33 | -0.09 | 0.00 | -0.00 | 47.82 | 0.00 | 47.90 | -0.00
0.04 | -0.16 | -0.07 | 0.05 | 0.00 | -0.00 | 47.82 | 0.00 | 47.89 | 0.00
0.05 | -0.07 | -0.18 | -0.02 | 0.00 | -0.00 | 47.82 | 0.00 | 47.89 | 0.00
0.06 | -0.10 | -0.14 | -0.00 | 0.00 | -0.00 | 47.82 | 0.00 | 47.89 | 0.00
0.07 | 0.01 | -0.30 | 0.06 | 0.00 | -0.00 | 47.82 | 0.00 | 47.89 | -0.00
0.08 | 0.13 | -0.46 | 0.10 | 0.00 | -0.00 | 47.82 | 0.00 | 47.90 | 0.00
0.09 | 0.02 | -0.32 | -0.01 | 0.00 | -0.00 | 47.82 | 0.00 | 47.90 | -0.00
0.10 | -0.01 | -0.28 | -0.04 | 0.00 | -0.00 | 47.82 | 0.00 | 47.89 | -0.00
0.10 | -0.12 | -0.41 | -0.01 | 0.02 | -0.00 | 47.82 | 0.00 | 47.90 | 0.00
0.12 | -0.02 | -0.54 | -0.00 | 0.02 | -0.00 | 47.81 | 0.01 | 47.89 | 0.00
0.13 | -0.06 | -0.50 | 0.07 | 0.02 | -0.00 | 47.82 | 0.01 | 47.89 | -0.00
0.14 | -0.07 | -0.49 | -0.18 | 0.02 | -0.00 | 47.81 | 0.01 | 47.89 | 0.00
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

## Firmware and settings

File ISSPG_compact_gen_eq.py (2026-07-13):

import re
import os
import math
import numpy as np
import sys
import time

# ═══════════════════════════════════════════════════════════════════
#   BEARING LOOKUP CLASS
# ═══════════════════════════════════════════════════════════════════
class bearings_discrete:
    def __init__(self, idRequiredMM, odRequiredMM=0):
        # Bearing dataset entered according to e1102 in [idMM,odMM,widthMM,massKG] format pg no b10-12
        if odRequiredMM != 0 :
            self.data_bearings = [
            [10,19,5,0.005],[12,21,5,0.006],[15,24,5,0.007],[17,26,5,0.007],
            [20,32,7,0.017],[25,37,7,0.021],[30,42,7,0.024],
            [35,47,7,0.027],[44.45,53.975,6.35,0.031],[40,52,7,0.031],[45,58,7,0.038],[50,62,6,0.036],
            [50,65,7,0.050],[55,72,9,0.081],[60,78,10,0.103],[65,85,10,0.128],
            [70,90,10,0.134],[75,95,10,0.149],[80,100,10,0.151],[85,110,13,0.263],
            [90,115,13,0.276],[95,120,13,0.297],[100,125,13,0.31],[105,130,13,0.324],
            [110,140,16,0.497],[120,150,16,0.537],[130,165,18,0.758],[140,170,18,0.832],
            [150,190,20,1.15],[160,200,20,1.23]
            ]
            self.indexBearing = 0
            while self.data_bearings[self.indexBearing][1] < odRequiredMM:
                self.indexBearing += 1            
        else :
            self.data_bearings = [
            [10,19,5,0.005],[12,21,5,0.006],[15,24,5,0.007],[17,26,5,0.007],
            [20,32,7,0.017],[25,37,7,0.021],[28,52,12,0.096],[30,42,7,0.024],
            [32,58,13,0.122],[35,47,7,0.027],[40,52,7,0.031],[45,58,7,0.038],
            [50,65,7,0.050],[55,72,9,0.081],[60,78,10,0.103],[65,85,10,0.128],
            [70,90,10,0.134],[75,95,10,0.149],[80,100,10,0.151],[85,110,13,0.263],
            [90,115,13,0.276],[95,120,13,0.297],[100,125,13,0.31],[105,130,13,0.324],
            [110,140,16,0.497],[120,150,16,0.537],[130,165,18,0.758],[140,170,18,0.832],
            [150,190,20,1.15],[160,200,20,1.23]
            ]
            self.indexBearing = 0
            while self.data_bearings[self.indexBearing][0] < idRequiredMM:
                self.indexBearing += 1

    def getBearingIDMM(self):
        return self.data_bearings[self.indexBearing][0]
    def getBearingODMM(self):
        return self.data_bearings[self.indexBearing][1]
    def getBearingWidthMM(self):
        return self.data_bearings[self.indexBearing][2]
    def getBearingMassKG(self):
        return self.data_bearings[self.indexBearing][3]

class nuts_and_bolts_dimensions:
    def __init__(self, bolt_dia, bolt_type="socket_head"):
        self.bolt_dia  = bolt_dia
        self.bolt_type = bolt_type
        self.bolt_head_dia, self.bolt_head_height = self.get_bolt_head_dimensions(diameter=self.bolt_dia, bolt_type=self.bolt_type)
        self.nut_width_across_flats, self.nut_depth = self.get_nut_dimensions(diameter=self.bolt_dia)

    def get_bolt_head_dimensions(self, diameter, bolt_type="socket_head"):
        diameter = float(diameter)

        socket_head_table = {
            1.6: {"d2": (3.00), "k": (1.60)},
            2.0: {"d2": (3.80), "k": (2.00)},
            2.5: {"d2": (4.50), "k": (2.50)},
            3.0: {"d2": (5.50), "k": (3.00)},
            4.0: {"d2": (7.00), "k": (4.00)},
            5.0: {"d2": (8.50), "k": (5.00)},
            6.0: {"d2": (10.00), "k": (6.00)},
            8.0: {"d2": (13.00), "k": (8.00)},
            10.0: {"d2": (16.00), "k": (10.00)}
        }

        # Only dk is stored for CSK, t is calculated as (dk - d) / 2
        csk_table = {
            3.0: {"dk": 6},
            4.0: {"dk": 8},
            5.0: {"dk": 10},
            6.0: {"dk": 12},
            8.0: {"dk": 16},
            10.0: {"dk": 20},
            12.0: {"dk": 24},
            16.0: {"dk": 30},
            20.0: {"dk": 36}
        }

        if bolt_type == "socket_head":
            spec = socket_head_table.get(diameter)
            if not spec:
                raise ValueError(f"Socket head bolt M{diameter} not found.")
            return [spec["d2"], spec["k"]]  # Return d2, k

        elif bolt_type == "CSK":
            spec = csk_table.get(diameter)
            if not spec:
                raise ValueError(f"CSK bolt M{diameter} not found.")
            dk = spec["dk"]
            t = (dk - diameter) / 2
            return [dk, round(t, 3)]  # Rounded for clarity

        else:
            raise ValueError("bolt_type must be 'socket_head' or 'CSK'")

    def get_nut_dimensions(self, diameter):
        diameter = float(diameter)

        nut_table = {
            2.0: {"width_across_flats": 4, "height": 1.6},
            2.5: {"width_across_flats": 5, "height": 2},
            3.0: {"width_across_flats": 5.5, "height": 2.4},
            4.0: {"width_across_flats": 7, "height": 3.2},
            5.0: {"width_across_flats": 8, "height": 4},
            6.0: {"width_across_flats": 10, "height": 5},
            7.0: {"width_across_flats": None, "height": 5.5},  # ISO not defined
            8.0: {"width_across_flats": 13, "height": 6.5},
            10.0: {"width_across_flats": 16, "height": 8},
            12.0: {"width_across_flats": 18, "height": 10},
            14.0: {"width_across_flats": 21, "height": 13},
            16.0: {"width_across_flats": 24, "height": 13},
            18.0: {"width_across_flats": 27, "height": 15},
            20.0: {"width_across_flats": 30, "height": 16},
            24.0: {"width_across_flats": 36, "height": 18},
            27.0: {"width_across_flats": 40, "height": 20},
            30.0: {"width_across_flats": 43, "height": 22},
        }

        spec = nut_table.get(diameter)
        if not spec:
            raise ValueError(f"No nut data found for bolt diameter M{diameter}")

        width_across_flats = spec["width_across_flats"]
        height = spec["height"]

        return [width_across_flats, height]

class motor:
    
    def __init__(self,
                 motor_OD                     = 92.6,
                 stator_ID                    = 55,
                 motor_rotor_base_thickness   = 2.6,
                 motor_rotor_base_ID          = 51,
                 rotor_height                 = 21.6,
                 rotor_ID                     = 82.6,
                 motor_stator_extrusion_depth = 1.5,
                 motor_stator_extrusion_dia   = 68,
                 stator_height                = 22,
                 stator_OD                    = 81,
                 stator_top_rotor_top_offset  = 4.8,
                 stator_hole_dia              = 3,
                 stator_hole_PCD              = 63,
                 motor_rotor_hole_num         = 6,
                 motor_rotor_hole_dia         = 4.2,
                 motor_rotor_hole_PCD         = 62,
                 motor_height                 = 26.4,
                 maxMotorAngVelRPM            = 5040,  # RPM
                 maxMotorTorque               = 1.3,   # Nm
                 maxMotorPower                = 1.3 * 5040 * 2*np.pi/60,  # W
                 motorMass                    = 0.265, # KG
                 motorName                    = "RO100"):

        self.motorName = motorName

        # Physical geometry
        self.motor_OD                     = motor_OD
        self.stator_ID                    = stator_ID
        self.motor_rotor_base_thickness   = motor_rotor_base_thickness
        self.motor_rotor_base_ID          = motor_rotor_base_ID
        self.rotor_height                 = rotor_height
        self.rotor_ID                     = rotor_ID
        self.motor_stator_extrusion_depth = motor_stator_extrusion_depth
        self.motor_stator_extrusion_dia   = motor_stator_extrusion_dia
        self.stator_height                = stator_height
        self.stator_OD                    = stator_OD
        self.stator_top_rotor_top_offset  = stator_top_rotor_top_offset
        self.stator_hole_dia              = stator_hole_dia
        self.stator_hole_PCD              = stator_hole_PCD
        self.motor_rotor_hole_num         = motor_rotor_hole_num
        self.motor_rotor_hole_dia         = motor_rotor_hole_dia
        self.motor_rotor_hole_PCD         = motor_rotor_hole_PCD   
        self.motor_height                 = motor_height

        #Motor other param
        self.maxMotorAngVelRPM            = maxMotorAngVelRPM
        self.maxMotorAngVelRadPerSec      = maxMotorAngVelRPM * (2 * np.pi / 60)
        self.maxMotorTorque               = maxMotorTorque
        self.maxMotorPower                = maxMotorPower
        self.massKG                       = motorMass     # kg

    # ------------------------------------------------------------------
    # Convenience getters (mirror reference code style)
    # ------------------------------------------------------------------
    
    # Maximum motor angular velocity in rad/s
    def getMaxMotorAngVelRadPerSec(self):
        return self.maxMotorAngVelRadPerSec
    
    # Maximum motor power in W
    def getMaxMotorPower(self):
        return self.maxMotorPower
    
    # Maximum motor torque in Nm
    def getMaxMotorTorque(self):
        return self.maxMotorTorque
    
    # Mass of the motor in kg
    def getMassKG(self):
        return self.massKG

    def getMotorODMM(self):
       return self.motor_OD

    def getMotorHeightMM(self): 
        return self.motor_height

    def getStatorIDMM(self):  
        return self.stator_ID

    def printParameters(self):
        print(f"Motor: {self.motorName}")
        print(f"  motor_OD           = {self.motor_OD} mm")
        print(f"  motor_height       = {self.motor_height} mm")
        print(f"  stator_ID          = {self.stator_ID} mm")
        print(f"  stator_hole_PCD    = {self.stator_hole_PCD} mm")
        print(f"  rotor_height       = {self.rotor_height} mm")

class motor_driver:
    def __init__(self, driver_name, motor_driver_data):
        self.driver_name                          = driver_name
        self.driver_upper_holes_dist_from_center  = motor_driver_data["driver_upper_holes_dist_from_center"]
        self.driver_lower_holes_dist_from_center  = motor_driver_data["driver_lower_holes_dist_from_center"]
        self.driver_side_holes_dist_from_center   = motor_driver_data["driver_side_holes_dist_from_center"]
        self.driver_mount_holes_dia               = motor_driver_data["driver_mount_holes_dia"]
        self.driver_mount_inserts_OD              = motor_driver_data["driver_mount_inserts_OD"]
        self.driver_mount_thickness               = motor_driver_data["driver_mount_thickness"]
        self.driver_mount_height                  = motor_driver_data["driver_mount_height"]

        # self.print_vars()
    
    def print_vars(self):
        print("driver_name:", self.driver_name)
        print("driver_upper_holes_dist_from_center: ", self.driver_upper_holes_dist_from_center)
        print("driver_lower_holes_dist_from_center: ", self.driver_lower_holes_dist_from_center)
        print("driver_side_holes_dist_from_center: ", self.driver_side_holes_dist_from_center)
        print("driver_mount_holes_dia: ", self.driver_mount_holes_dia)
        print("driver_mount_inserts_OD: ", self.driver_mount_inserts_OD)
        print("driver_mount_thickness: ", self.driver_mount_thickness)
        print("driver_mount_height: ", self.driver_mount_height)
        print("---")

class internalsingleStagePlanetaryGearbox:
    def __init__(self, 
                 design_params,
                 gear_standard_parameters,
                 Ns                        = 20,
                 Np                        = 40,
                 Nr                        = 100,
                 module                    = 0.5,
                 numPlanet                 = 3,
                 fwSunMM                   = 5.0,
                 fwPlanetMM                = 5.0,
                 fwRingMM                  = 5.0,
                 maxGearAllowableStressMPa = 400,
                 densityGears              = 1246,
                 densityStructure          = 1246,
                 ):
        
        self.Ns        = Ns
        self.Np        = Np
        self.Nr        = Nr
        self.numPlanet = numPlanet
        self.module    = module

        self.maxGearAllowableStressMPa = maxGearAllowableStressMPa # MPa
        self.maxGearAllowableStressPa  = maxGearAllowableStressMPa * 10**6 # Pa
        self.densityGears              = densityGears
        self.densityStructure          = densityStructure
        self.bhnSun                    = 270 # Brinell Hardness Number for sun gear
        self.bhnPlanet                 = 270 # Brinell Hardness Number for planet gear
        self.bhnRing                   = 270 # Brinell Hardness Number for ring gear
        self.enduranceStressSunMPa     = 2.75*self.bhnSun - 69    # MPa
        self.enduranceStressPlanetMPa  = 2.75*self.bhnPlanet - 69 # MPa
        self.enduranceStressRingMPa    = 2.75*self.bhnRing - 69   # MPa
        self.youngsModulusSun          = 2.05 * 10**5 # MPa 
        self.youngsModulusPlanet       = 2.05 * 10**5 # MPa 
        self.youngsModulusRing         = 2.05 * 10**5 # MPa 
        self.equivYoungsModulusSP      = (2.0 * self.youngsModulusSun * self.youngsModulusPlanet) / (self.youngsModulusSun + self.youngsModulusPlanet)
        self.equivYoungsModulusPR      = (2.0 * self.youngsModulusPlanet * self.youngsModulusRing) / (self.youngsModulusPlanet + self.youngsModulusRing)

        # Face width of sun gear, planet gear, and ring gear in mm
        self.fwSunMM    = fwSunMM
        self.fwRingMM   = fwRingMM
        self.fwPlanetMM = fwPlanetMM

        # Face width of sun gear, planet gear, and ring gear in m
        self.fwSunM     = fwSunMM / 1000.0
        self.fwRingM    = fwRingMM / 1000.0
        self.fwPlanetM  = fwPlanetMM / 1000.0

        # Coefficient of friction and Pressure Angles
        self.mu            = gear_standard_parameters["coefficientOfFriction"] # 0.3 # Coefficient of friction
        self.pressureAngle = gear_standard_parameters["pressureAngleDEG"]      # 20  # deg

        self.planetMinDistanceMM = design_params["planetMinDistanceMM"]        # mm
        
        self.sCarrierExtrusionDiaMM       =  design_params["sCarrierExtrusionDiaMM"]       # 8.0 # mm
        self.sCarrierExtrusionClearanceMM =  design_params["sCarrierExtrusionClearanceMM"] # 1.0 # mm
    
    #------------------------------------
    # Constraints
    #------------------------------------
    def geometricConstraint(self):
        return (self.Ns + 2*self.Np == self.Nr) 
    
    def meshingConstraint(self):
        return ((self.Ns + self.Nr) % self.numPlanet == 0)

    def noPlanetInterferenceConstraint_old(self):
        return 2*(self.Ns + self.Np)*self.module*np.sin(np.pi/self.numPlanet) >= 2*self.module*self.Np + self.planetMinDistanceMM

    # New incorporates the extrusion diameter
    def noPlanetInterferenceConstraint(self):
        Rs                        = (self.module) * self.Ns / 2
        Rp                        = (self.module) * self.Np / 2 
        numPlanet                 = self.numPlanet
        sCarrierExtrusionRadiusMM = self.sCarrierExtrusionDiaMM * 0.5
        return 2 * (Rs + Rp) * np.sin(np.pi/(2*numPlanet)) - Rp - sCarrierExtrusionRadiusMM >= self.sCarrierExtrusionClearanceMM * 2

    #------------------------------------
    # Gear ratio
    #------------------------------------
    def gearRatio(self):
        return (self.Nr + self.Ns) / self.Ns

    #-------------------------------------------------------------------------
    # Uitility Functions
    #-------------------------------------------------------------------------
    def inverse_involute(self,inv_alpha):
        # This is an approximation of the inverse involute function
        alpha  = ((3*inv_alpha)**(1/3) - 
                  (2*inv_alpha)/5 + 
                  (9/175)*(3)**(2/3)*inv_alpha**(5/3) - 
                  (2/175)*(3)**(1/3)*(inv_alpha)**(7/3) - 
                  (144/67375)*(inv_alpha)**(3) + 
                  (3258/3128125)*(3)**(2/3)*(inv_alpha)**(11/3) - 
                  (49711/153278125)*(3)**(1/3)*(inv_alpha)**(13/3))
        return alpha

    def involute(self,alpha):
        return (np.tan(alpha) - alpha)

    # Define the differentiable quadratic approximation of the min function
    def quadratic_min(self, a, b, k=0.01):
        return (a + b - np.sqrt((a - b)**2 + k**2)) / 2
    
    #-------------------------------------------------------------------------
    # Gear Tooth profile parameters
    #-------------------------------------------------------------------------
    def getPressureAngleRad(self):
        return self.pressureAngle * np.pi / 180  # Pressure angle in radians

    def getWorkingPressureAngle(self):
        module = self.module  # Module of the gear
        Ns     = self.Ns
        Np     = self.Np
        Nr     = self.Nr
        xs     = 0.0 # self.PSCs
        xp     = 0.0 # self.PSCp
        xr     = 0.0 # self.PSCr
        
        #---------------------------------
        # Pressure Angle
        #---------------------------------
        alpha = self.getPressureAngleRad()

        #---------------------------------
        # Working pressure angle
        #---------------------------------
        # Sun-Planet
        inv_alpha_w_sunPlanet = 2*np.tan(alpha)*((xs + xp)/(Ns + Np)) + self.involute(alpha)
        alpha_w_sunPlanet = self.inverse_involute(inv_alpha_w_sunPlanet)

        # Planet-Ring
        inv_alpha_w_planetRing = 2*np.tan(alpha)*((xr-xp)/(Nr - Np)) + self.involute(alpha)
        alpha_w_planetRing = self.inverse_involute(inv_alpha_w_planetRing)

        return alpha_w_sunPlanet, alpha_w_planetRing

    def getCenterDistModificationCoeff(self):
        module = self.module  # Module of the gear
        Ns     = self.Ns
        Np     = self.Np
        Nr     = self.Nr
        xs     = 0.0 # self.PSCs
        xp     = 0.0 # self.PSCp
        xr     = 0.0 # self.PSCr
        
        #------------------------------
        # Pressure Angle
        #------------------------------
        alpha = self.getPressureAngleRad()  # Pressure angle in radians

        #------------------------------
        # Working pressure angle
        #------------------------------
        alpha_w_sunPlanet, alpha_w_planetRing = self.getWorkingPressureAngle()

        #------------------------------
        # Centre distance modification coefficient
        #------------------------------
        y_sunPlanet  = ((Ns + Np) / 2) * ((np.cos(alpha) / np.cos(alpha_w_sunPlanet)) - 1)
        y_planetRing = ((Nr - Np) / 2) * ((np.cos(alpha) / np.cos(alpha_w_planetRing)) - 1)

        return y_sunPlanet, y_planetRing

    def getCenterDistance(self):
        module = self.module  # Module of the gear
        Ns     = self.Ns
        Np     = self.Np
        Nr     = self.Nr
        xs     = 0.0 # self.PSCs
        xp     = 0.0 # self.PSCp
        xr     = 0.0 # self.PSCr

        #-------------------------------
        # Centre distance modification coefficient
        #-------------------------------
        y_sunPlanet, y_planetRing = self.getCenterDistModificationCoeff()

        #-------------------------------
        # Centre distance
        #-------------------------------
        centerDist_sunPlanet = ((Ns + Np)/2  + y_sunPlanet)* module
        centerDist_planetRing = ((Nr - Np)/2  + y_planetRing)* module

        return centerDist_sunPlanet, centerDist_planetRing

    def getBaseDia(self):
        module = self.module  # Module of the gear
        Ns     = self.Ns
        Np     = self.Np
        Nr     = self.Nr
        xs     = 0.0 # self.PSCs
        xp     = 0.0 # self.PSCp
        xr     = 0.0 # self.PSCr

        # Pressure Angle
        alpha = self.getPressureAngleRad() # Rad

        # Reference Diameter
        D_sun    = module * Ns # Sun's reference diameter
        D_planet = module * Np # Planet's reference diameter
        D_ring   = module * Nr # Ring's reference diameter

        # Base Diameter
        D_b_sun    = D_sun * np.cos(alpha)
        D_b_planet = D_planet * np.cos(alpha)
        D_b_ring   = D_ring * np.cos(alpha)

        return D_b_sun, D_b_planet, D_b_ring

    def getTipCircleDia(self):
        module = self.module  # Module of the gear
        Ns     = self.Ns
        Np     = self.Np
        Nr     = self.Nr
        xs     = 0.0 # self.PSCs
        xp     = 0.0 # self.PSCp
        xr     = 0.0 # self.PSCr

        #----------------------------
        # Pressure Angle
        #----------------------------
        alpha = self.getPressureAngleRad() # Rad

        #----------------------------
        # Reference Diameter
        #----------------------------
        D_sun    = module * Ns # Sun's reference diameter
        D_planet = module * Np # Planet's reference diameter
        D_ring   = module * Nr # Ring's reference diameter

        #----------------------------
        # Center Distance Modification Coefficient
        #----------------------------
        y_sunPlanet, y_planetRing = self.getCenterDistModificationCoeff()

        #----------------------------
        # Tip circle diameter
        #----------------------------
        # Sun
        D_a_sun = D_sun + 2 * module * (1 + y_sunPlanet - xp)

        # Planet
        D_a_planet = D_planet + 2 * module * (1 + self.quadratic_min((y_sunPlanet - xs), xp))  
        # D_a_planet = D_planet + 2 * module * (1 + self.quadratic_min((y_planetRing - xs),xp)) 
        # D_a_planet = D_planet + 2 * module * (1 + xp) 
        
        # Ring
        D_a_ring = D_ring - 2 * module * (1 - xr)
        
        return D_a_sun, D_a_planet, D_a_ring

    def getTipPressureAngle(self):
        module = self.module  # Module of the gear
        Ns     = self.Ns
        Np     = self.Np
        Nr     = self.Nr
        xs     = 0.0 # self.PSCs
        xp     = 0.0 # self.PSCp
        xr     = 0.0 # self.PSCr
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

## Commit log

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2025-07-16 Added correct equation files
    [Opt_singleStagePlanetaryGBOptimization.py]
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2025-07-16 Bug Fix in equation file
    [Opt_singleStagePlanetaryGBOptimization.py]
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2025-07-28 Bug fix in DSPG
    [Opt_doubleStagePlanetaryGBOptimization.py]
2025-08-03 changes in cpg and mass bug fix
    [Opt_compoundPlanetaryGBOptimization.py]
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2025-08-07 in the previous commit the material denisty is correctly entered. -- #30
    [Opt_compoundPlanetaryGBOptimization.py, Opt_doubleStagePlanetaryGBOptimization.py, Opt_singleStagePlanetaryGBOptimization.py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]
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2025-08-27 added SSPG final code, corrected density, fixed max gb dia, separate gen_eq_file, bearing mass added to results, provision for optimizing for a given gear-ratio, provision for printing the optimizati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
    [Opt_singleStagePlanetaryGBOptimization.py]
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2025-08-31 completed the dspg code, added wpg outer bearing mass and actuator width, fixed the bearing mass bug in WPG, yet the cpg, wpg, and dspg actuator widths are set to 0. will correct them in next code
    [Opt_doubleStagePlanetaryGBOptimization.py]
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2025-08-31 corrected a small bug in dspg
    [Opt_doubleStagePlanetaryGBOptimization.py]
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2025-09-16 added stiffness data and plot files
    [stiffness_20250908_161640.csv, stiffness_20250908_172116.csv]
2025-09-16 added transmission stiffness properly
    [transmission_stiffness_cpg.csv, transmission_stiffness_sspg.csv]
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2026-06-22 ISSPG: Update mass function for two CAD designs
    Problem
    =======
    1. Mass function update required for the new ISSPG designs.
    Solution
    ========
    1. Changed the equation of fw_s_used.
    2. Changed the mass function according to the recent changes in the CAD.
    Note
    ====
    1. Added result file for RO60.
    2. Added ISSPG_inside_gen_eq.py and ISSPG_compact_gen_eq.py for the two different cads.
    [ISSPG_BRUTEFORCE_MIT_RO100.csv, ISSPG_BRUTEFORCE_MIT_RO60.csv, ISSPG_BRUTEFORCE_MIT_RO80.csv]
2026-06-22 Updated Parse file to work with ISSPG Problem ======= Few variables which were newly added to the onshape CAD have to be updated in parse file
    Update parse_variables_txt.py to include number variables
    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
    [ISSPG_inside_gen_eq.py]
2026-06-22 Updated json files
    The range of fesable gearboxes was little due to carrier extrusion diameter being 8.
    Density of PLA mismatched that of PLA given in Onshape
    Changed the value of carrier extrusion diameter to 7 and clearance to 0.5.
    Chnaged density value so that mass function gives correct value.
    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
2026-07-01 Added Optimization Code for Inrunner Compound Planetary Gearbox type1
    Writing optimization code for Inrunner Compound Planetary Gearbox type1 to find the optimal design parameters for a given motor and gear ratio.
    Added a new python file InrunnerCPG_type1_gen_eq.py which contains the optimization code.
    Wrote the mass function.
    Added incpg_params.json file to store the parameters.
    Added Results file.
    Updated the density of aluminum in the config.json file to 2700 from 2710.
    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
    [INCPG_BRUTEFORCE_MIT_RI100.csv]
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2026-07-01 Updated Parse file to work with INCPG
    Few variables which were newly added to the onshape CAD have to be updated in parse file
    Updated parse_variables_txt.py to include number variables
    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
2026-07-01 Added new variables, Updated mass function
    The CAD ran into some errors due to ring_radial_width being used for gearbox casing thickness.
    Added a new variable for gearbox thickness and updated the mass fucntion accordingly
    Changed name of gearbox from type 1 to independent
    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
    [InrunnerCPG_independent_gen_eq.py]
2026-07-01 Added Constraints for Sun PCD, Planet PCD in Inrunner CPG
    1. Sun gear became smaller than sun shaft bearing ID.
    2. Planet gear became smaller than planet bearing OD if minimum number of teeth on planet gear is 28 but the constraint should be on PCD.
    3. Primary Planet Gear had smaller number of teeth that Secondary Planet Gear in some cases.
    1. Added constraint for Sun PCD to be greater than Sun Shaft Bearing ID.
    2. Added constraint for Planet PCD to be greater than Planet Bearing OD.
    3. Added constraint for Primary Planet Gear to have greater number of teeth than Secondary Planet Gear.
    1. Changed the max gearbox dia mult factor from 0.8 to 0.85 t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
    [InrunnerCPG_independent_gen_eq.py]
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2026-07-03 Updated Mass function and setvariables for changes in CAD.
    Mass function and setvariables should be updated to accomodate for the changes in CAD.
    Updated the mass fucntion and setvariables.
    Chnaged the no carrier constraint from 1*module to 1.25*module
    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
    [InrunnerCPG_independent_gen_eq.py]
2026-07-03 Added Optimisation code for Inrunner CPG (dependent)
    Optimizing the INCPG (dependent) actuator
    Added all the files required to run optimization.
    Dependent means that the motor can not run without the gearbox attached.
    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
    [InrunnerCPG_dependent_gen_eq.py, Opt_dependentInrunnerCompoundPlanetaryGBOptimization.py]
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2026-07-08 Removed a file, Minor changes in files.
    ISSPG_outside_gen_eq.py file was not needed anymore.
    Deleted the file.
    Updated result file output fields.
    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
    [ISSPG_compact_gen_eq.py, ISSPG_inside_gen_eq.py, InrunnerCPG_dependent_gen_eq.py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]
2026-07-09 Added new optimization script for both types of ISSPG
    To run each file for ISSPG, we had to change the optimization script for inside and compact type.
    Created a new optimization script so both types of ISSPG work without changing the optimization script.
    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
    [ISSPG_compact_gen_eq.py, ISSPG_inside_gen_eq.py, Opt_inBearingInternalSingleStagePlanetaryGBOptimization.py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]
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2026-07-22 fixed the inrunner RI100 parameters
    [insspg_motor_config.json]
2026-07-22 added an isssue to fix the motor parameters and pipeline in issues.md
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2026-07-23 fix the cad errors in ICPG and INSSPG (both types)
    [motor_config.json]
2026-08-06 Added Optimisation code for Inrunner WPG (compact) Problem ======= Optimizing the INWPG (compact) actuator
    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
2026-08-12 Updated Mass function Problem ======= Updating Mass Function The values taken of motor in Opt_INWPG needed to be taken for config file Solution ======== Updated the Mass Function Made changes in the 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
    [insspg_motor_config.json]
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2026-09-16 added needle bearing variable and changed some fixed bearing selection to id_dependent variable selection . added some contraint for 2nd stage planet OD . tested for RI80 motor too .
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2026-09-24 Updated some variables Problem ======= MAD motor max diameter generated some cad errors Solution ======== Fixed the error by changing the definition of Motor case OD
    Also changed the value of sun hub dia
    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
2026-10-15 Add golden-output regression check for all gearbox optimisers
    tests/golden/golden.py runs every gearbox type in actOpt.GEARBOX_DISPATCH
    with every motor its run() supports, and compares the returned
    opt_parameters and the CAD equation files written against stored
    baselines. Groups that write the same CADs/ folder run one after another;
    other groups run in parallel.
    Baselines (46 cases) record current behaviour, including known bugs.
    One gear ratio per family (6.5 single-stage, 10 compound, 20 double-stage
    and Wolfrom), lowered for RO80/RI80 cases that only reach low ratios.
    ISSPG with RO60 finds no design at any ratio from 4 to 30, so those two
    cases record 'no feasible design'.
    Co-Authore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
2026-10-15 Add smoke tests, ruff/codespell config and CI workflow
    - tests/test_smoke.py: dispatch targets exist, one print block per
    gearbox type, every Opt module imports and supports a motor, config
    files are valid JSON, every case has a golden baseline
    - pyproject.toml: ruff (pyflakes, syntax errors, bare except) and
    codespell settings; both report-only in CI for now
    - .github/workflows/checks.yml: compile, pytest and report-only lint on
    every push; golden check on manual dispatch
    - requirements-dev.txt, tests/README.md
2026-10-15 Create results folders before writing optimiser CSVs
    results/ is no longer tracked, so fresh clones have no
    results/results_BruteForce_<motor>/ folders and most optimisers crashed
    with FileNotFoundError on their first run. Create the folder before each
    CSV write, as ICPG and INSSPG already did.
    Golden check: all 40 non-DSPG cases unchanged, run with no results/
    folder present.
2026-10-15 Use GEAR_RATIO_STEP in the gear-ratio bin filter
    The full-sweep filter checked gearRatio() <= gearRatioIter + 1, so any
    step other than 1 gave overlapping or skipped bins. Affects WPG, DSPG,
    IDSPG, INDSPG and INWPG (dependent and independent).
    No result change: all five configs use GEAR_RATIO_STEP = 1. Golden check:
    all 40 non-DSPG cases unchanged.
2026-10-15 Create Equation_Files/<motor>/ folders before writing per-ratio CAD files
    A full sweep (--gr 0) writes one equation file per gear ratio into
    CADs/<TYPE>/Equation_Files/<motor>/ and crashed when that folder did not
    exist (e.g. DSPG only had U8 and MAD_M6C12). Create it first in the 17
    per-ratio writers of SSPG, CPG, WPG, DSPG, INCPG and INWPG, as ICPG,
    IDSPG, INDSPG and INSSPG already did.
    Checked by calling each writer with a motor that has no folder. Golden
    check: all 40 non-DSPG cases unchanged.
2026-10-15 Add the missing per-ratio equation writer to ISSPG
    A full sweep (--gr 0) called Actuator.genEquationFile(...), which neither
    ISSPG variant defined, so it crashed with AttributeError. Add
    genEquationFile writing to
    CADs/ISSPG/Equation_Files/<motor>/isspg_equations_<LL>_<UL>_onshape.txt
    like the other gearboxes, and let genEquationFile_editCADdirectly take an
    optional output path so both share one writer.
    Checked: actOpt.py --motor RO100 --gb_type isspg_inside --gr 0 now
    completes and writes 31 per-ratio files. Golden check: all 40 non-DSPG
    cases unchanged.
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2026-10-15 Round the module step in SSPG, ISSPG and INSSPG searches
    The module loop did module += 0.1 with no rounding, giving
    0.7999999999999999, 0.8999999999999999, ... in the CSV and CAD equation
    files whenever the chosen module is 0.8 or more. With MODULE_MIN = 0.8 it
    would also have skipped 1.2. Round to 0.1 like the other gearboxes, which
    already round right after the increment.
    Golden check: the 16 SSPG/ISSPG/INSSPG cases are unchanged (their chosen
    modules are 0.5-0.7, reached before the drift starts).
2026-10-15 Record missing IDSPG CAD model as a bug in ISSUES.md
    IDSPG is a supported gearbox type and writes CAD equation files, but no
    Onshape link or CAD model was ever committed, so its results can't be
    checked in CAD. The result-changing fixes are on hold until it is added.
2026-10-15 Add material-modes task (3D-printed / metal) to ISSUES.md
    Records the decided design: --material 3dp|metal (default 3dp), PLA/PLA
    vs steel/aluminium (7850 kg/m3, 400 MPa / 2700 kg/m3), all 15 gearbox
    types, always-metal parts such as the INDSPG rotor coupler stay aluminium.
    Two follow-up tasks: split the ring gear into steel teeth and aluminium
    housing, and give metal mode its own thicknesses and clearances.
2026-10-15 Fix INDSPG 3D-printed mode: PLA gears and stage-2 parts, aluminium rotor
    Opt_INDSPG passed densityGears = Aluminium (with PLA gear strength), and
    the actuator reused densityGears as the rotor coupler's aluminium density.
    Stage 2 then took densityGears for all its printed parts, so the stage-2
    ring, carrier, planets, second carrier and bearing retainer were weighed
    as aluminium (2700) instead of PLA (1240).
    - Opt_INDSPG: gears, structure and gear strength are all PLA, matching
    the 3D-printed mode of every other gearbox
    - New densityRotor setting (aluminium) for the rotor coupler, the only
    metal part in the 3D-printed build
    - Stage 2 uses the structure density, like stage 1
    - Rename densi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
2026-10-15 Clarify in ISSUES.md that the rotor coupler is the only metal part
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2026-10-15 Record results CSVs (mass, efficiency, cost, part masses) in golden baselines
    The baselines held only the chosen design and the CAD equation files, so a
    fix that changes mass but not the design (e.g. the INDSPG stage-2 density
    fix) passed unnoticed.
    - Each case now runs in its own temporary working directory; the results
    CSVs it writes are stored in the baseline (run-time lines removed) and
    the repo's results/ folder is no longer touched by checks
    - Changed CSVs are reported value by value, e.g. mass: 1.483 -> 1.192
    - Re-recorded all 46 baselines: design, CAD files and errors are
    identical to the previous baselines; only results_files is added
    - Checked: a second pass over the 40 non-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
2026-10-15 Mark the missing IDSPG CAD link (bug 3) as resolved in ISSUES.md
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2026-10-15 Correct the Steel properties in indspg_motor_config.json
    Steel held PLA values (1245.6 kg/m3, 70 MPa). Set 7850 kg/m3 and 400 MPa,
    as in a13fee0. Unused in 3D-printed mode; no result change.
2026-10-15 ISSPG compact: weigh the sun-2 bearing that the geometry actually uses
    setVariables() picks the sun-2 bearing by outer diameter (the rotor-base
    opening), and the CAD uses that bearing. getMassKG_3DP() then looked the
    bearing up again by its bore, which uses the other bearing table in
    bearings_discrete and can return a different bearing (ISSUES.md bug 1).
    Store the selected bearing's mass in setVariables() and use it.
    RO100: CAD bearing 50x62x6 (36 g), was weighed as 50x65x7 (50 g)
    RO80: CAD bearing 40x52x7 (31 g), was weighed as 40x50x6 (23 g)
    Results (chosen design and CAD files unchanged):
    isspg_compact RO100 @6.5: mass 1.013 -> 0.999 kg, torque density 25.67 -> 26.03
    isspg_comp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
2026-10-15 INCPG: weigh the rotor bearings that are actually configured
    INCPG independent picks its rotor top and bottom bearings per motor from
    the config (RI100: 40x50x6 and 30x42x7; RI80: 35x47x7 and 25x37x7), but
    the mass used fixed RI100 values (0.023 and 0.024 kg) for both motors.
    INCPG dependent typed in its bottom bearing mass (0.007 kg) the same way.
    - New CommonComponents.bearing_mass_kg(id, od, width): mass of the bearing
    with exactly that size, raising ValueError if it is not in the tables.
    Matching the full size avoids the ID-lookup trap (a 25 mm bore lookup
    returns 25x32x4, not the configured 25x37x7).
    - INCPG independent and dependent store the selected bearings' masses in
    setVa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
2026-10-15 Log oversized OD bearing lookups and INSSPG type 2 bearings as bugs 5 and 6
    - Bug 5: INSSPG (rotor support, rotor upper support) and ISSPG compact
    (sun-2) size a bearing from a maximum OD, but bearings_discrete's OD
    lookup returns the first bearing with OD >= that value, so the chosen
    bearing is 0.5-3.5 mm larger than the space. Table of current picks,
    reproduce snippet, probable fix (largest bearing that fits), needs an
    Onshape check.
    - Bug 6: which rotor support bearings INSSPG type 2 uses is unknown; its
    mass uses typed-in 6.6 + 7.9 g.
    - #TODO comments at the four code locations pointing to these entries
    - Update line numbers in bugs 2 and 4, which had shifted
    Comments only;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
2026-10-15 Log IDSPG double-counted bearing masses as bug 7 in ISSUES.md
    Was only mentioned under bug 3's 'Blocks'. Includes the stage 1 / stage 2
    line numbers, the size of the error (24 g for RO100 at ratio 20), the
    probable fix and two related open questions.
2026-10-15 Add #TODO comments for the IDSPG double-counted bearings (bug 7)
    One above each stage total in ActuatorandGearbox_IDSPG.py (lines 1913 and
    2127); bug 7's line numbers in ISSUES.md updated for the shift. Comments
    only; golden check for idspg unchanged.
2026-10-16 Add motors_draft.md: collected motor datasheet values (not read by code)
    Working draft for the planned motors.json: decided conventions (peak
    torque, no-load speed, torque-source order, wire-slot clearance rule), the
    complete U8 Lite entry with measured mounting and wire-slot values, and
    the specs collected so far for the T-Motor U / U10 Plus / MN, Vector
    Technics, MAD EEE and frameless RI / RO motors, with open questions.
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2026-10-16 motors_draft.md: U10 Plus rotor mount swapped to M4 @ 23 (primary), M3 @ 21
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2026-10-17 ISSUES: log RO100 rotor screw size (M4 vs M5) mismatch as bug 8
2026-10-17 Motor draft: settle RO100 rotor height and offset, point screw size to bug 8
2026-10-17 Confirm RO100 710 g and RO80 352 g; ISSPG motor masses are wrong
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2026-10-17 DSPG: take any framed motor from motors.json (Phase 2 step 4)
    Opt_DSPG.run() builds the motor with load_motor(). The MAD_M6C12-only 1.25x
    gearbox-diameter allowance is now the small-motor rule (below 80 mm) in
    dspg_params.json. SSPG, CPG, WPG and DSPG now ask load_motor for a
    framed_outrunner, so a frameless motor name gives a clear error.
    Results change (golden dspg baselines re-recorded under the new motor names;
    U8 -> U8_Lite 0.958 -> 0.970 kg, peak torque 45.7 -> 54.4 Nm
    U10 -> U10_Plus_KV80 1.273 -> 1.325 kg, 68.5 -> 86.2 Nm
    MN8014 1.222 -> 1.215 kg, 98.1 -> 94.7 Nm
    VT8020 -> VT8020_PRO 1.533 -> 1.442 kg, 76.4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
2026-10-17 Frameless outrunners: ICPG, ISSPG and IDSPG take motors from motors.json (Phase 2 step 5)
    Opt_ICPG, Opt_ISSPG_inside, Opt_ISSPG_compact and Opt_IDSPG build the motor
    with load_motor(name, motor_type="frameless_outrunner"), replacing their
    own motor copies (ISSPG's had wrong RO100/RO80 masses, RO100 rotor height,
    offset and M5 rotor screw; IDSPG used the class defaults). Each run() now
    accepts any frameless outrunner; load_motor rejects a motor of another type.
    Diameter limits are unchanged (ICPG: inside the stator; IDSPG: motor OD +
    clearance, stage 1 inside the stator).
    Results change (golden baselines re-recorded): gears are now sized with the
    datasheet peak torque (RO100 12 Nm, RO80 4 Nm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
2026-10-17 Frameless inrunners: INSSPG, INCPG, INWPG and INDSPG take motors from motors.json (Phase 2 step 6)
    Opt_INSSPG, Opt_INCPG_dependent/independent, Opt_INWPG_dependent/independent
    and Opt_INDSPG build the motor with load_motor(name,
    motor_type="frameless_inrunner"), replacing the hard-coded RI100 copy
    (INCPG dependent) and the reads of insspg_motor_config.json /
    indspg_motor_config.json motor entries. INCPG independent and both INWPG
    files no longer load insspg_motor_config.json at all (they used it only for
    motors). Diameter limits are unchanged.
    Results change (golden baselines re-recorded): peak torque is now the
    datasheet peak (RI100 4.95 Nm, RI80 4.10 Nm) instead of Kv-based continuous
    tor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
2026-10-17 Remove the old motor copies and make motor values required (Phase 2 step 7)
    - Delete the Motors sections from config.json, motor_config.json,
    idspg_motor_config.json, indspg_motor_config.json and
    insspg_motor_config.json (nothing reads them now; this drops U12 and U15)
    and the unused MAX_GB_DIA_MULT_FACTOR_MAD_M6C12 key in idspg_params.json.
    - motor_framed_outrunner, motor_frameless_outrunner and
    motor_frameless_inrunner have no default values any more, so a missing
    motor value is an error instead of silently using U12/RO100/RI100 numbers.
    - README and actOpt --motor help point to config_files/motors.json and use
    the new motor names.
    - ISSUES.md bug 8: ISSPG's own RO100 copy is g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
2026-10-17 Onshape: push_to_onshape(gb_type) with one-time model setup
    set_values.py no longer needs editing per gearbox: the equations file
    follows from --gb_type and the Variable Studio URL comes from a personal,
    gitignored Onshape_extension/onshape_models.json (template:
    onshape_models.example.json, one entry per gearbox type).
    Before writing it saves an Onshape version (rollback point) and writes
    nothing if that fails; after writing it reads the variables back and lists
    any that did not take. Version URLs (/v/) are refused.
    Tests use a fake client (no network): the equations file matches what each
    optimiser writes, the call order is version -> write -> read, mismatches are
    reported, and nothing i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
2026-10-17 actOpt --onshape: optimise and update the Onshape model in one command
    After a successful run, --onshape pushes the result with
    push_to_onshape(gb_type). No design, a missing setup or an API error only
    prints a one-line message; the optimisation result is already saved. Off by
    default, so normal runs and the golden check never contact Onshape.
    README: the Onshape steps become 'list your models once in
    onshape_models.json, then add --onshape'.
2026-10-17 ISSUES: CAD 2 - new WPG Onshape model is view-only and cannot be copied
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2026-10-17 ISSUES: CAD 3 - DSPG stage-1 ring split; save the case and add set_values --file
    The equations files and results CSV of the run that shows the split ring
    (MAD_M6C06_KV140, dspg, ratio 20) are saved in
    docs/cad_issues/CAD3_dspg_MAD_M6C06_KV140_gr20/. set_values.py --file pushes
    such a saved file, so the case can be replayed in Onshape without
    re-optimising. Tests check every saved case still parses.
2026-10-18 ISSUES: record per-gearbox settings to unify (config files, FOS, driver, diameter rules)
    Found while building the common runner. Five config files give different
    PLA densities (1250 / 1245.6 / 1240 / 1240.06) and two of them give
    aluminium and steel PLA values; ISSPG hard-codes FOS 1.2 / service factor
    1.5; the motor driver is passed as OdrivePro, None or not at all; and the
    maximum-gearbox-diameter rule differs per type. Each fix changes results,
    so each is its own later commit.
2026-10-18 Replace the 14 Opt_*.py files with one gearbox runner (Phase 3a)
    gearbox_runner.py holds one GearboxSpec per gearbox type: only what
    differs between types (classes, config and params files, optimiser kind,
    max-diameter formulas, driver, FOS, extra densities). run(gb_type, motor,
    gear_ratio) builds the motor, gearbox, actuator and optimiser from it.
    Every existing difference is kept exactly, including the order of each
    diameter formula, so results are bit-identical.
    - actOpt.py calls gearbox_runner.run; the 200-line if/elif print chain is a
    small layout table (output checked identical for all 82 stored results,
    including the ICPG and INSSPG mass breakdowns). --gb_type now lists the
    val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
2026-10-22 Golden check: one metal case per gearbox type; ISSUES: material modes done
    golden.py adds a metal-mode case for each gearbox type (its first golden
    motor), id <case>__metal, and a --material filter; _run_case passes the
    mode to the runner. Smoke tests check that each type gets PLA/PLA in 3dp
    and steel/aluminium in metal mode, and the _metal results suffix.
    All 57 golden cases match (42 3D-printed unchanged, 15 new metal).
2026-10-22 README: rewrite for new users (427 -> 153 lines)
    One quick-start command with an options table, one table of all 15 gearbox
    types (motor kind, example, Onshape link, view-only marker), motors,
    material modes, CAD (Onshape / SolidWorks) and developer pointers. Details
    move to docs/ (onshape, gearboxes, motors). The INSSPG type 1/2 vs
    dependent/independent mapping is left open (unconfirmed). The SolidWorks
    path is corrected to CADs/<TYPE>/<type>_actuator/<type>_actuator.SLDASM.
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
